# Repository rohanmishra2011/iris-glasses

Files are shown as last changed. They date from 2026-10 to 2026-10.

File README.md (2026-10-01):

# PUPIL / IRIS Smart Glasses

PUPIL is an offline Raspberry Pi 5 smart-glasses prototype for object-memory support during early cognitive decline. It uses a glasses-mounted webcam, YOLO11n object detection, a waist-mounted MPU6050 IMU, local SQLite memory, Vosk speech-to-text, Qwen2.5 0.5B fallback query logic, and Piper text-to-speech.

The system is designed to answer questions such as “PUPIL, where is my phone?” without sending indoor camera, voice, or memory data to the cloud.

## Repository structure

```text
.
├── main.py                     # Main runtime loop
├── imu.py                      # MPU6050 walking / turn / room-transition logic
├── nlp.py                      # Voice-command intent handling and memory answers
├── object_database.py          # Local SQLite object memory
├── stt.py                      # Vosk wake-word and speech recognition
├── tts.py                      # Piper speech output
├── vision_context.py           # Room-context inference from detected objects
├── shared_state.py             # Live shared system state
├── configs/                    # Runtime configuration files
├── docs/                       # Architecture, testing, safety and roadmap notes
├── hardware/3d-models/         # 3D-printable prototype enclosure files
├── models/                     # Model setup notes and small config files only
├── results/                    # Graphs and CSVs used in project evaluation
└── tools/                      # Testing and graph-generation scripts
```

## Hardware

- Raspberry Pi 5
- Logitech C270 webcam / microphone
- MPU6050 waist-mounted IMU
- MAX98357A I2S amplifier
- 4Ω speaker
- Power bank
- 3D-printed glasses / electronics enclosure

The STL files for the current prototype are in `hardware/3d-models/`.

## Runtime

On the Raspberry Pi:

```bash
python -m venv .venv
source .venv/bin/activate
python -m pip install -r requirements-pi.txt
./run_pi.sh
```

## Model files

Large model binaries are intentionally not committed to GitHub. Place them locally when deploying:

- `models/yolo11n.pt`
- `models/en_US-lessac-medium.onnx`
- `models/vosk-model-small-en-us-0.15/`

Small model configuration files, setup notes, and reproducible testing code are included.

## Privacy and safety

PUPIL is a research prototype, not a medical device. It does not diagnose dementia, replace a caregiver, or guarantee exact object location. The main privacy design choice is that object detection, speech processing, memory lookup, and response generation run locally on the device.

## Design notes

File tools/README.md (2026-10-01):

# Tools

Small scripts used for prototype testing and presentation results.

- `live_yolo_threshold_test.py` opens a live OpenCV webcam window and compares YOLO precision/recall across confidence thresholds.
- `experimental_methodology_graph.py` generates the experimental-methodology setup graph.

These are not required for the normal Raspberry Pi runtime.

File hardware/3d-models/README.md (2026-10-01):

# 3D model files

This folder contains the 3D-printable enclosure parts used for the current PUPIL smart-glasses prototype.

| File | Source file found on laptop | Notes |
| --- | --- | --- |
| `body.stl` | `Body4.stl` | Main body component found in the Desktop `Glasses` folder. |
| `rpi_lid_or_body2.stl` | `Body2.stl` | Second body/lid-style component found in the Desktop `Glasses` folder. The original filename did not explicitly say “lid.” |
| `rpi_casing_body.stl` | `RPiCasingBody.stl` | Raspberry Pi casing body. |

No file literally named “RPI lid” was found, so the likely matching body/lid STL was preserved with a descriptive filename.

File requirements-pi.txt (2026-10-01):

# Raspberry Pi 5 / Python 3.11 runtime. Create a fresh venv on the Pi.
--extra-index-url https://download.pytorch.org/whl/cpu
numpy>=1.26,<3
opencv-python>=4.10,<5
torch==2.8.0+cpu
torchvision==0.23.0
ultralytics>=8.3,<9
sounddevice>=0.5,<1
vosk>=0.3.45,<1
piper-tts>=1.3,<2
smbus2>=0.5,<1

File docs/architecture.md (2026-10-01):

# Architecture

VSGlasses begins as a modular monolith. Stable domain models and typed ports
separate application behavior from camera, model-runtime, tracking, and output
implementations.

Current dependency direction:

```text
runtime/bootstrap -> application -> ports + domain
adapters ------------------------> ports + domain
domain --------------------------> standard library only
```

Perception produces observations, not decisions. Detection, short-term tracking,
long-term memory, and reasoning are separate responsibilities.

The current detector adapter uses the OpenCV Zoo NanoDet COCO model. Its output
is converted into framework-independent `Detection` models before a class-aware
IoU tracker associates observations. Track IDs are short-lived session
identifiers and must never be stored as permanent object identity.

Optional hardware must never be imported or initialized by domain code. The
composition root selects configured adapters. Missing optional devices are
reported through health state and do not prevent unrelated capabilities from
starting.

## Public-boundary rules

1. Framework-specific objects do not cross port boundaries.
2. Frames receive UTC and monotonic timestamps at acquisition.
3. Queues are bounded; live operation favors recent frames over stale backlog.
4. Configuration is validated at startup and passed explicitly.
5. Components have explicit lifecycle and health behavior.
6. Future packages are added only when their development phase begins.

## Speech boundary

Speech is kept outside perception and object memory:

```text
local microphone -> wake/follow-up gate -> conversation model -> answer text
                                                |              -> TTS queue
                                                v
                                      approved memory tools
```

`SpeechSynthesizer` is a port. Platform commands such as macOS `say` and Linux
`espeak` are adapters. `SpeechOutputService` owns a bounded worker queue, so
slow playback cannot delay acquisition or inference. Missing engines disable
speech output without preventing application startup.

The optional Vosk microphone adapter implements `SpeechRecognizer`.
`VoiceCommandService` continuously runs blocking single-utterance recognition
on a background worker. It discards unaddressed household speech locally,
opens on a configured wake phrase, and maintains a short follow-up window.
Recognition pauses while an answer is expected to be spoken so the system does
not converse with its own TTS output. Microphone code does not call the
database, detector, or TTS adapter directly.

## Familiar-person boundary

```text
camera frame -> YuNet landmarks -> SFace embedding -> temporary session cluster
                                                        |
                           spoken name + relationship -> confirm
                                                        |
                                                        v
                                              local profile database
```

The face analyzer owns OpenCV-specific alignment and embedding extraction.
`FaceIdentityService` associates faces with visible person tracks, clusters
unknown embeddings, and requires conservative multi-frame agreement for known
profiles. `SQLitePersonProfileRepository` stores only explicitly confirmed
names, owner-relative relationships, and embeddings in a database separate
from object observations. Raw images never cross into persistence.

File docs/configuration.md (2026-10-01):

# Configuration

`configs/default.toml` defines safe defaults. Deployment-specific files override
only values that differ. Configuration must be loaded and validated once during
startup; application modules receive typed settings rather than reading files or
environment variables directly.

Hardware components declare `enabled` and `required` independently. Current
camera configuration defaults to optional so the runtime can start and report a
degraded state when no webcam is connected.

The camera `source` is either `camera` or `video`. Camera sources use `device`;
video sources require `video_path` and may set `loop_video`. `preview` is
disabled by default because unattended and headless deployments may not have a
GUI.

Reconnect delays use bounded exponential backoff beginning at
`reconnect_delay_seconds` and capped at `max_reconnect_delay_seconds`.

`perception.inference_fps` controls detector frequency independently from camera
capture. Confidence, NMS, tracking IoU, and missed-update thresholds are
configuration values so Raspberry Pi performance and scene behavior can be
evaluated without source changes.

NanoDet post-processing applies confidence-ordered, class-aware suppression.
`perception.nms_threshold` controls ordinary same-class overlap suppression.
A containment check additionally removes smaller nested duplicates, such as a
second person box drawn inside a higher-confidence full-body person box, without
suppressing overlapping boxes from different object classes.

An empty `perception.allowed_labels` list enables all COCO classes. Supplying
labels restricts output to those exact COCO class names.
`tracking_max_missed_updates` retains an invisible dormant track through short
occlusions, while `tracking_reappearance_distance_pixels` bounds how far a
reappearing observation may move and still recover the prior internal ID.

`output.jsonl_enabled` controls metadata-only structured perception output.
Records are appended to `output.jsonl_path`; raw images are never written by
this sink. Internal track IDs and UTC first/last-seen timestamps are retained
for downstream software even though track IDs are hidden from the user-facing
camera overlay.

`memory.enabled` controls local SQLite object memory. `memory.database_path`
selects the database file. SQLite is part of Python's standard library and does
not add a separate service dependency.

`speech.enabled` controls optional speech output. `speech.engine` is `auto`,
`say`, or `espeak`; `speech.rate` is validated from 80 to 400 words per minute.
`speech.queue_size` bounds pending utterances, and
`speech.speak_query_answers` controls whether object-memory answers are spoken.
Speech is disabled by default. If enabled without an installed engine, the
application logs a warning and continues without audio.

`speech_input.enabled` controls always-listening offline recognition.
`speech_input.model_path` selects an extracted Vosk model directory;
`device = -1` uses the operating system's default microphone. Sample rate,
audio block size, and per-utterance listening timeout are configurable.
`wake_phrases` lists local phrases that open voice attention, and
`conversation_window_seconds` controls how long natural follow-ups remain
addressed without another wake phrase. Unaddressed transcripts are discarded
before the conversation model is called. Missing libraries, models, or
microphones disable voice attention without stopping visual perception.

`face_identity.enabled` controls familiar-person recognition. YuNet and SFace
model paths and the separate profile database path are explicit. Face inference
runs at its own bounded rate. Recognition requires the configured cosine
threshold, runner-up margin, and repeated-frame vote count. Sample interval and
diversity settings prevent consecutive near-identical frames from filling a
profile. Automatic enrollment questions require one unambiguous visible face,
enough varied samples, working speech input/output, and the prompt cooldown.
Unconfirmed clusters are memory-only and expire at
`temporary_ttl_seconds`.

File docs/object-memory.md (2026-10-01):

# Local object memory

The object memory is deterministic and metadata-only. It does not store raw
images and does not let a language model query SQLite directly.

SQLite data is stored at `data/object_memory.sqlite3`. The versioned schema
contains:

- `sessions`: start and end UTC timestamps;
- `observations`: session-local track ID, COCO class, confidence, UTC timestamp,
  camera source, and bounding box.

An indexed `(label, observed_at_utc)` lookup supports last-seen queries across
sessions. Track IDs are not permanent physical identity.

## Conversational questions

Click **Ask** in the OpenCV window, type a question, and press Enter:

```text
Where was the phone last seen?
Have you seen my mobile anywhere?
Could you help me find the bottle?
Do you remember seeing my backpack?
```

Development configuration uses a local Ollama language model for open-ended,
multi-turn conversation. It retains recent chat history for follow-up
questions:

```text
You: Have you seen my bottle?
VSGlasses: Bottle was last seen at Wednesday at 10:15.
You: When did you see it?
VSGlasses: Bottle was last seen at Wednesday at 10:15.
```

The model can converse normally, but it cannot access the database. For every
claim about whether or when the camera saw an object, it must invoke the single
approved `lookup_object_last_seen` tool. The tool resolves supported detector
labels and returns deterministic evidence from object memory. Unsupported or
unseen objects are reported as such.

If the local model runtime is unavailable, the application reports that
conversation is unavailable. It does not silently substitute a phrase-based
interpreter for the configured Ollama model.

## Session summary

On clean shutdown, one summary reports duration, observation count, unique
session tracks, and labels observed. Per-object lifecycle messages are disabled
by default.

## Privacy

No raw frames are stored. Database retention, deletion, encryption, and user
consent controls must be designed before patient deployment.

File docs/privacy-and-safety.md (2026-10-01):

# Privacy and safety

VSGlasses is local-first. Raw frames must not be persisted by default. Any future
capture, biometric enrollment, cloud synchronization, or caregiver access must
have an explicit purpose, consent model, retention policy, deletion path, and
security review.

Perception results are uncertain observations. They must not be represented as
medical conclusions or safety guarantees.

## Familiar-person profiles

Familiar-person recognition is opt-in and local. The live camera frame is
converted directly to an embedding and discarded; the application does not
persist face photographs. Unnamed clusters are session-only and disappear when
the process stops. A permanent profile is created only after the owner states a
name and explicitly confirms the interpreted name and relationship.

Relationships such as `daughter` are stored only when the owner states them.
They must never be inferred from appearance. Unknown people remain `Unknown`;
the closest profile is not presented as fact unless the configured threshold,
runner-up margin, and multi-frame confirmation all pass.

`data/face_profiles.sqlite3` contains biometric embeddings and must be treated
as sensitive data. Profiles require a user-facing deletion path before wider
deployment. This feature is assistive context, not liveness-protected identity
proof, authentication, or access control.

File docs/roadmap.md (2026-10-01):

# Roadmap

1. Engineering foundation
2. Reliable camera acquisition
3. Evaluated object-detection baseline
4. Short-term object tracking
5. Perception reliability and long-duration hardening
6. Observational event contracts
7. Long-term object and location memory
8. Consent-based familiar-person recognition
9. Optional IMU-based mobility perception
10. Deterministic task and context modeling
11. Optional speech and conversation
12. Navigation and caregiver integration

Each phase requires measurable exit criteria before downstream features begin.
The familiar-person phase now has an initial local implementation. Live
accuracy, enrollment usability, deletion controls, spoof resistance, and
Raspberry Pi performance still require acceptance testing before it can be
considered complete.

The intended personalization and spatial-learning architecture is described in
`adaptive-household-learning.md`. Language-model conversation is always on;
household learning, user modeling, and spatial mapping remain separate
evidence-based subsystems.

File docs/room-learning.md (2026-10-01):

# Room-learning prototype

This isolated prototype evaluates whether DINOv2 visual embeddings can
recognize user-taught rooms from new camera views. It does not modify object
memory, conversation, navigation, or the main runtime.

Only normalized embedding vectors and room names are stored in
`data/room_embeddings.json`. Raw room frames are held in memory during capture
and are not written to disk.

## Setup

Install the optional dependencies:

```bash
source .venv/bin/activate
python -m pip install -r requirements-location.txt
```

The first teach or recognize command downloads `facebook/dinov2-small` from
Hugging Face and caches it locally. Later runs use the cache.

## Teach from the main camera

Launch the normal application after installing the optional dependencies:

```bash
python main.py --config configs/development.toml
```

In the camera window:

1. Click the `T` button or press the `T` key.
2. Type a room name and press Enter.
3. Move the camera slowly to show several angles of the room.
4. Wait for `Learned <room name>` at the bottom of the preview.

Encoding happens on a background thread after capture, so the camera preview
remains responsive. The first teaching session may take longer while DINOv2
loads.

Taught-room matching remains a separate personalized signal. It checks stored
DINOv2 embeddings in the background and stabilizes them using visual
similarity, recent history, and weak object context.

## Generic room type without teaching

The top-right room label is independent of teaching. Every five seconds,
`qwen3-vl:4b` receives a compressed JPEG through the local Ollama API and
classifies the visible scene as a generic room type such as kitchen, bedroom,
bathroom, or hallway. It does not read `data/room_embeddings.json`.

Install the model once:

```bash
ollama pull qwen3-vl:4b
```

Each completed classification updates the room immediately, while insufficient
visual evidence produces `Room: Unknown`.

## Room-aware object memory

Once the semantic room label is known, visible object observations store that
stable room alongside their time and tracking metadata. Conversation lookups
can therefore answer that an object was last seen in a particular room. Frames
classified as `Unknown` are stored without a room rather than being assigned an
uncertain location. Existing SQLite memories are migrated automatically and
retain their earlier observations with an empty room field.

Object memory also stores conservative visible support relationships. When a
small, confident object detection is contained within a much larger detected
bed, couch, chair, or dining table, the sighting can be recorded as `on top of`
that reference object. Otherwise, the nearest separate confident object can be
stored as `next to` when both boxes are genuinely close in the 2D image.
Both relationships can be retained together, such as `on top of the bed and
next to the bottle`.
Left/right/behind claims remain excluded because they are unreliable from one
camera view.

Spatial relationships require three consistent inference frames before they
become current-scene facts or persistent memory. Confirmed relationships decay
gradually across brief detector dropouts instead of disappearing after one
unstable frame.

## Proactive awareness

When speech output is enabled, VSGlasses announces only selected stable scene
changes: entering a different known room, a person remaining visible for three
inference frames, or a newly confirmed spatial relationship. Repeated events
use a twenty-second cooldown. Ordinary object appearances are not narrated.
These values are configurable in `[awareness]`.

Voice input supports a true microphone sleep state. Say `PUPIL, go to
sleep` or press `S` to close microphone capture. Since a closed microphone
cannot hear a wake phrase, press `W` to resume listening. Restarting the
application also starts awake.

## Live scene awareness

The conversation model has a separate grounded tool for the latest camera
inference. It includes the stabilized current room, visible object counts, and
current spatial relationships. Questions such as `What room am I in?`, `What
can you see?`, and `What is next to the phone?` use this ephemeral snapshot.
Historical questions such as `Where did you last see the phone?` continue to
use SQLite object memory instead.

The live snapshot is hybrid. Every semantic vision update sends Qwen3-VL both
the clean camera JPEG and NanoDet's current labels. The grounded conversation
tool keeps NanoDet counts and Qwen3-VL's independently verified object list
separate, allowing the answer to use both signals without persisting a
vision-model guess as historical object memory.

## Teach rooms

Stand in a room and run:

```bash
python tools/location/room_learning.py teach --room kitchen
```

Move the camera slowly to show different walls, furniture, and viewing angles.
The default capture stores twelve embeddings. Repeat from meaningfully
different positions:

```bash
python tools/location/room_learning.py teach --room kitchen
```

Teach at least one contrasting room:

```bash
python tools/location/room_learning.py teach --room bedroom
```

List taught rooms:

```bash
python tools/location/room_learning.py list
```

## Evaluate recognition

From a new viewpoint, run:

```bash
python tools/location/room_learning.py recognize
```

The command averages evidence from five new views and prints the best accepted
room, similarity, and margin over the runner-up. It returns an uncertain result
when either the absolute similarity or separation from the second-best room is
too low.

Defaults:

- minimum similarity: `0.70`;
- minimum best-versus-runner-up margin: `0.04`.

These are prototype thresholds, not validated safety limits. Record results
under daylight, artificial light, changed furniture, people present, and
similar-looking rooms before integrating recognition into VSGlasses.

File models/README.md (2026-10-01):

# Model files

Large model binaries are intentionally not committed to GitHub.

Expected local deployment files:

- `yolo11n.pt` for YOLO11n object detection
- `en_US-lessac-medium.onnx` for Piper speech output
- `vosk-model-small-en-us-0.15/` for offline speech recognition

The small Piper JSON config is committed because it is lightweight and useful for deployment. Downloaded model weights should stay local on the Raspberry Pi or development machine.

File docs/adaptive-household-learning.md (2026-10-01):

# Adaptive household learning

VSGlasses should become personalized without silently retraining its language
model on a vulnerable person's private life. Adaptation is therefore split into
explicit, inspectable memory systems rather than unrestricted online weight
updates.

## Always-on language understanding

Every non-empty user utterance passes through the configured local Ollama
model. There is no phrase router or deterministic conversation mode. The model
receives recent dialogue context and may call narrowly scoped application tools.
Object sightings remain factual database records; the model cannot query or
write SQLite directly.

## Household knowledge

A future household knowledge graph should learn user-confirmed entities and
relationships:

- preferred names for people, objects, and rooms;
- which objects usually belong to which person;
- usual storage locations such as keys near the entrance;
- recurring routines and user preferences;
- confidence, evidence, and last-confirmed time for every learned fact.

New facts must be reversible, attributable to evidence, and correctable through
conversation. Low-confidence inferences must be phrased as suggestions, not
facts.

## Spatial learning

Learning the shape of a home requires a separate mapping subsystem, not an LLM.
The intended progression is:

1. user-labeled rooms and fixed camera locations;
2. visual place recognition for revisiting known rooms;
3. visual-inertial odometry using camera and IMU motion;
4. local SLAM for a metric or topological map;
5. room transitions, landmarks, and object locations attached to that map.

Raw frames should remain ephemeral by default. Derived landmarks, embeddings,
poses, and maps require retention controls, encryption, export, and deletion.
The system must expose uncertainty when localization is weak or the environment
changes.

## Behavioral personalization

Personalization should begin with retrieval and statistics:

- frequently requested objects;
- typical activity times;
- repeated navigation destinations;
- reminder acceptance or dismissal patterns;
- preferred response length, voice, and terminology.

These signals should modify ranking, reminders, and response context through a
versioned user profile. They should not automatically fine-tune the foundation
model. Any later model training must use an explicit consent flow, an isolated
dataset, offline evaluation, rollback, and a clear benefit over retrieval-based
personalization.

## Safety boundaries

- Never infer a diagnosis, medication decision, or emergency from routine data.
- Never identify an unfamiliar person as familiar without consent and evidence.
- Never claim a room, route, or object location above its measured confidence.
- Provide controls to inspect, correct, forget, export, and disable learning.
- Keep conversation, perception, spatial mapping, and personal memory as
  separate components connected through typed tools.

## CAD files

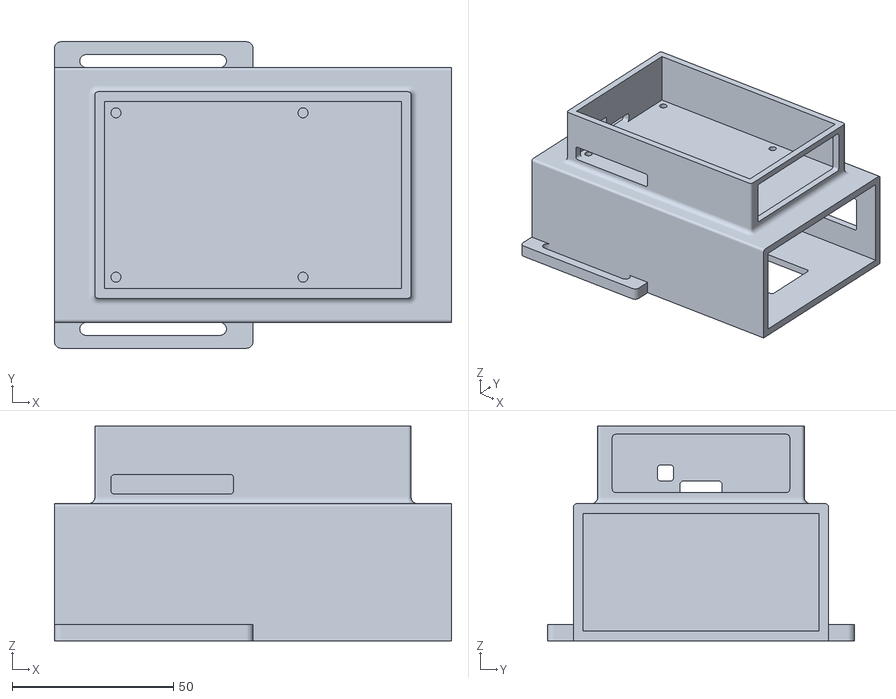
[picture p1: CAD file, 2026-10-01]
hardware/3d-models/rpi_casing_body.stl
123.0 x 95.0 x 66.5

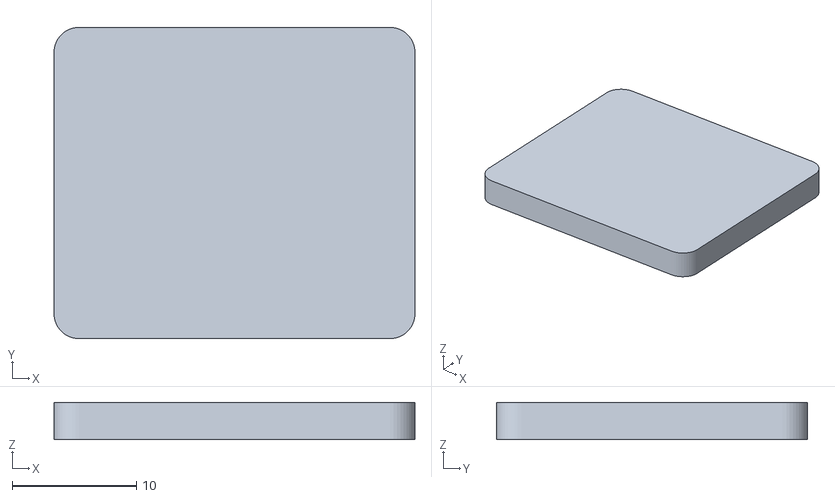
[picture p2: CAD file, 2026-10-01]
hardware/3d-models/body.stl
29.0 x 25.0 x 3.00

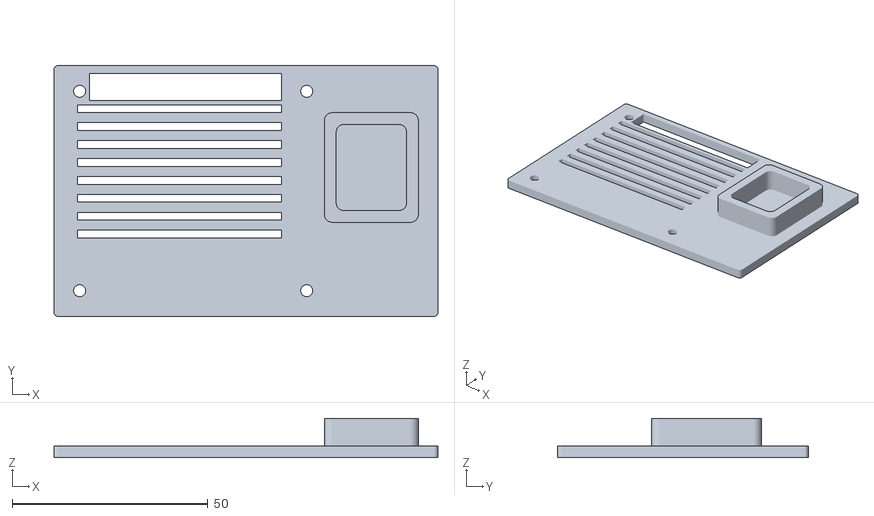
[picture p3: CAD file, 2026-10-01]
hardware/3d-models/rpi_lid_or_body2.stl
98.0 x 64.0 x 10.0

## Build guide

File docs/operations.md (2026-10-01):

# Operations

## Startup

Activate the project virtual environment and validate configuration:

```bash
source .venv/bin/activate
vsglasses --check-config
vsglasses --config configs/raspberry_pi.toml
```

For interactive development with a live window, use the single root entry
point:

```bash
python main.py
```

On macOS, camera capture, inference, and the Cocoa-backed OpenCV window run on
the main thread because OpenCV's AVFoundation capture can crash when its native
camera delegate is split from GUI lifecycle across Python threads. The
Raspberry Pi service runtime retains bounded background acquisition.

The default camera is optional. If OpenCV is missing, the USB camera is absent,
or a read fails, acquisition reports a recovering state and retries with bounded
exponential backoff. Other application capabilities remain available.

Use `Ctrl+C` or send `SIGTERM` for a clean shutdown. Camera resources and waiting
frame consumers are released during shutdown.

## Diagnostics

Use `--run-seconds N` for bounded diagnostic runs. Acquisition metrics include
successful frames, open failures, read failures, reconnects, overwritten stale
frames, and effective average FPS.

Raw frames are held only in a one-item in-memory latest-frame buffer. They are
not persisted by the acquisition service.

## Validation

Run normal tests with `pytest`. Tests marked `hardware` require connected
peripherals and should be run separately on the Raspberry Pi. Before completing
Phase 1 validation, perform camera disconnect/reconnect testing and an eight-hour
soak test on the target Raspberry Pi. The exact commands and evidence checklist
are documented in `phase-1-validation.md`.

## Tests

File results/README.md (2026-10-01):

# Results

Graphs and CSV outputs used to summarize prototype testing for the research paper and presentation.

These files document latency optimization, object-location retrieval accuracy, methodology setup, and YOLO confidence-threshold testing.

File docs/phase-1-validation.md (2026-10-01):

# Phase 1 target-hardware validation

The software implementation is complete when normal automated checks pass.
Phase 1 is accepted for Raspberry Pi deployment only after the following
physical tests are recorded.

## USB camera smoke test

```bash
source .venv/bin/activate
VSGLASSES_RUN_HARDWARE_TESTS=1 pytest tests/hardware/test_usb_camera.py
```

## Disconnect and reconnect

1. Start `vsglasses --config configs/raspberry_pi.toml`.
2. Confirm frames are acquired.
3. Disconnect the webcam.
4. Confirm a recovering health state and bounded retry behavior.
5. Reconnect the webcam.
6. Confirm acquisition resumes without restarting the process.
7. Stop with `Ctrl+C` and confirm the device is released.

## Soak test

Run the helper for eight hours:

```bash
scripts/camera_soak_test.sh 28800
```

During and after the run, record:

- successful frames and effective FPS;
- open and read failures;
- reconnect count;
- process RAM and CPU;
- Raspberry Pi temperature;
- unexpected termination or unbounded resource growth.

Increase to 24 hours after the eight-hour run succeeds.

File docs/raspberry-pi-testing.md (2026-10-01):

# Raspberry Pi testing

Target: Raspberry Pi 5, 4 GB, 64-bit Raspberry Pi OS, Python 3.11, USB webcam.

## Transfer

Do not copy `.venv`, caches, generated output, or the local development
database. Virtual environments and compiled packages are operating-system and
CPU specific.

Transfer the source tree while excluding:

```text
.venv/
__pycache__/
.pytest_cache/
.mypy_cache/
.ruff_cache/
outputs/
data/
```

The ONNX file under `models/` must be included.

## Raspberry Pi preparation

```bash
sudo apt update
sudo apt install -y python3-venv python3-dev v4l-utils ffmpeg libgl1 libglib2.0-0

cd VSGlasses
python3 --version
python3 -m venv .venv
source .venv/bin/activate
python -m pip install --upgrade pip setuptools wheel
python -m pip install -r requirements.txt
python -m pip install -e .
```

Confirm the webcam:

```bash
v4l2-ctl --list-devices
VSGLASSES_RUN_HARDWARE_TESTS=1 pytest tests/hardware/test_usb_camera.py -v
```

## First interactive run

Run from the Raspberry Pi desktop:

```bash
python main.py --config configs/raspberry_pi_development.toml
```

Verify:

- the preview opens;
- Diagnostics toggles;
- object boxes appear;
- track recovery works after short occlusion;
- Ask returns a last-seen answer;
- clean shutdown prints one session summary;
- `data/object_memory.sqlite3` and `outputs/perception.jsonl` are created.

## Initial measurements

Record camera FPS, detection FPS, current and average inference latency, frame
latency, CPU, RAM, and temperature. Do not change the model until these baseline
numbers are captured.

Temperature:

```bash
vcgencmd measure_temp
```

After interactive validation, run the camera-only soak procedure in
`phase-1-validation.md`. A full perception soak command should be added after
the first Pi measurements establish sustainable inference settings.

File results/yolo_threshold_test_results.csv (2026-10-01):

threshold | image_trial | actual_objects | detected_objects | true_positives | false_positives | false_negatives | tp | fp | fn
0.4 | 1 | bottle, chair, laptop, phone | bottle, chair, laptop, phone | bottle, chair, laptop, phone |  |  | 4 | 0 | 0
0.4 | 2 | couch, dining table | chair, couch | couch | chair | dining table | 1 | 1 | 1
0.4 | 3 | book, couch, person, tv | bed, book, person, tv | book, person, tv | bed | couch | 3 | 1 | 1
0.4 | 4 | chair, microwave | chair, couch, microwave | chair, microwave | couch |  | 2 | 1 | 0
0.4 | 5 | bottle, sink | bottle, oven, person, refrigerator, sink | bottle, sink | oven, person, refrigerator |  | 2 | 3 | 0
0.4 | 6 | bed, chair, person, teddy bear, tv | bed, chair, person, tv | bed, chair, person, tv |  | teddy bear | 4 | 0 | 1
0.4 | 7 | bed, book | bed | bed |  | book | 1 | 0 | 1
0.4 | 8 | bed, book, person | bed, book, person | bed, book, person |  |  | 3 | 0 | 0
0.4 | 9 | bed, chair | bed, chair | bed, chair |  |  | 2 | 0 | 0
0.4 | 10 | book, desk | tv |  | tv | book, desk | 0 | 1 | 2
0.6 | 1 | bed, book, person | bed | bed |  | book, person | 1 | 0 | 2
0.6 | 2 | book, desk |  |  |  | book, desk | 0 | 0 | 2
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

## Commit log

2026-09-15 Prepare current Pupil smart glasses code snapshot
2026-10-01 Organize PUPIL code and hardware assets
    [body.stl, rpi_casing_body.stl, rpi_lid_or_body2.stl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]
